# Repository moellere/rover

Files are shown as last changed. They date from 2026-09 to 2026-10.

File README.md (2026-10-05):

# Grover

A small rover built from Makeblock parts, living on a garage workbench and
learning to look after itself. Named Grover on 2026-09-29: blue rails, and it
spends its life demonstrating *near... far*.

This repo is the whole project: a dated [journal](JOURNAL.md) of what
happened and who decided it, the [bill of materials](BOM.md) against a $100
budget, the [roadmap](ROADMAP.md), the off-board brain, printable hardware,
scripts, and a reference copy of the firmware.

It is a collaborative build between Enoch and Claude (Anthropic). The
journal records which model did the work at each stage and which decisions
were Claude-driven versus Enoch-directed. [CLAUDE.md](CLAUDE.md) is the
standing rulebook (mission, hard constraints, budget policy, permissions,
safety rules learned the hard way) - auto-loaded by Claude Code as project
instructions, and readable as plain English by anyone.

## The mission

1. **Phase 1 (current):** drive around the workbench without falling off.
2. **Phase 2:** recharge itself.
3. **Phase 3:** roam the house.

## Where it stands (2026-10-05)

- **Visual homing works.** `home_to_marker` finds a printed ArUco marker
  with the onboard camera and parks in front of it, unattended.
- **It has been through the house.** On 2026-10-04 Grover drove from the
  dining room through the foyer and living room to the kitchen doorway
  (~12-14 m) in short, camera-checked legs, stopping itself for a dog,
  people and sun glare. Hardwood and rugs both fine.
- **Spinal cord is an ESP32** (`rover32`, since 2026-10-03) with no I/O
  expander; the TFMini LiDAR sits alone on its own I2C bus.
- **Sensors:** TFMini forward LiDAR (obstacle stop at 50 cm), two TCRT5000
  cliff sensors on mounts that put each one ahead of its wheel, the rover
  camera, and two bench cameras (one behind, one head-on PTZ).
- **Chassis is the trike build** (two driven wheels, trailing caster). The
  swivel caster twists the rear on stops; a fixed printed skid
  (`hardware/caster-skid.scad`) replaces it next.
- **The house chassis works too:** a Eufy RoboVac 12 driven over IR from
  `blackcam`, a T-Camera on its lid (camera + IR LED driver). It has backed
  off its dock and returned on command.
- Known hazard: no rear cliff sensors, and reversing a trike is
  unpredictable - see the reversing rule in `CLAUDE.md`.

## Architecture

Three layers, decided early and still standing:

| Layer | Hardware | Role |
|---|---|---|
| **Spinal cord** | ESP32 devkit (`rover32`, since 2026-10-03; was a Wemos D1 Mini), ESPHome | reflexes: watchdog, disconnect-stop, cliff, battery and TFMini obstacle guards, kick start, optional brake-on-stop. Authoritative - nothing off-board can override them. |
| **Eyes** | TTGO T-Camera (ESP32-WROVER, OV2640), ESPHome | snapshot and stream endpoints; no decisions |
| **Brain** | `brain/` - Python + OpenCV, off-board | everything with judgment: marker detection, the homing loop, bounded drive pulses. Exposed as an MCP server (`rover-brain`). |

Claude (the model) is *not* in the control loop: it starts a run and reads
the log. A homing run is a plain Python loop - look, decide one pulse,
settle, look again - talking to the rover over ESPHome's native API.

## Hardware

- Chassis: Makeblock Starter Robot Kit, **trike** configuration; two DC gear
  motors, trailing swivel caster (to be replaced by a printed fixed skid)
- Controller: ESP32 devkit (`rover32`) - motor enables on GPIO16/17,
  direction on GPIO18/19/22/23, cliff inputs GPIO35/32, TFMini I2C on
  GPIO25/26, battery sense on GPIO34. (Was a Wemos D1 Mini + MCP23008.)
- Motor driver: L298N dual H-bridge
- Power: 3x 18650 Li-ion in 3S (12.6 V full); LM2596 buck at 5.2 V for the
  ESP32, the camera and the TFMini; battery voltage through a 100k/27k
  divider (calibrated to the meter). A 3S BMS board is in hand, not fitted.
- Sensing: Benewake TFMini LiDAR on a printed bracket (direct GH1.25 lead,
  5 V); two TCRT5000 cliff modules at 3.3 V on printed v4 mounts
- Vision: TTGO T-Camera on the rover (fisheye, ~111 deg); two Thingino
  cameras on the bench (`camv3` behind the rover, `fishcam` PTZ head-on)
- Homing targets: ArUco 4x4_50 markers, ids 0 (80 mm) and 1 (160 mm),
  printable from `hardware/markers/`

## Software

- **Firmware:** ESPHome (`firmware/rover32.yaml` for Grover,
  `firmware/blackcam.yaml` for the Eufy's lid board; `rover.yaml` and
  `eufy-ir.yaml` are retired - all reference copies; the live configs with
  secrets are in a private repo).
  Custom services `forward`/`backward`/`left`/`right`/`stop`; `Drive duty`
  `Pivot duty` and `Left trim` (+6 %, calibrated) sliders; a `Brake on stop` switch (boots off); `Obstacle stop` distance (50 cm).
- **Brain:** `brain/` - MCP tools `status`, `snapshot(bench|front|rover)`, `set_brake`, `set_obstacle_stop`,
  `drive` (capped at 1 s, refused on low battery or cliff), `find_marker`,
  `home_to_marker`, `stop`. Install with `scripts/install-brain.sh`; details
  in `brain/README.md`.
- **Printing:** parametric OpenSCAD in `hardware/` (camera cradle, adapter
  strip, TFMini bracket, cliff-sensor mounts, caster skid, marker pages, a
  shelved Roomba plug), sliced with the house rules
  (PETG, no brim, tree supports on auto) and printed through the
  print-warden service; toolchain via `scripts/install-tools.sh`.
- **Scripts:** `rover_ctl.py` (drive over the native API),
  `test_disconnect_safety.py` (proves the disconnect-stop),
  `camera_snapshot.py`, `warden_call.py` (talk to the print-warden from a
  shell). All read hosts and credentials from environment variables.

### Safety design

A device that can drive off a table needs more than "send stop when you
mean it." In the firmware, always on:

- **Command watchdog** - no drive command for 1.5 s -> motors stop.
- **Disconnect-stop** - the API client goes away for any reason -> motors
  stop. Verified by `scripts/test_disconnect_safety.py`.
- **Cliff guard** - a front IR sensor stops seeing the bench -> forward and
  pivots refused (backward stays allowed).
- **Battery guard** - below 9.3 V the rover refuses to drive; resumes above
  9.6 V. Rolling 25 s average, ignored for 20 s after boot (a latched-low
  bug from a bad first sample was fixed 2026-10-05).
- **Obstacle guard** - the TFMini (polled every 50 ms) refuses and cuts
  forward motion inside 50 cm; "was under 60 cm, now too close to measure"
  counts as an obstacle (a wall met at an angle slipped through before).
- **Kick start** - 100 ms at full power from rest so both wheels break
  stiction together, then the set duty and trim.
- **Brake-on-stop** (switch, boots off) - shorts the windings for 150 ms on
  every stop. Measured: no change in distance and it didn't stop the
  end-of-pulse yaw (the swivel caster did that).

The brain adds courtesy limits on top (pulse cap, gap between pulses,
lost-marker and stuck detection) but never replaces the firmware's.

## The house chassis: a Eufy RoboVac 12

Phases 2 and 3 ride on a **Eufy RoboVac 12**, keeping its own docking,
charging, cliff and bumper behaviour, driven over infrared. Its remote
sends a 6-byte frame `68 CMD HH MM 5C SUM` - **the current time is stamped
into every command**, and stale frames are ignored. `blackcam`, a T-Camera
on the lid (`firmware/blackcam.yaml`), stamps each frame from SNTP and
drives a 940 nm LED through an NPN transistor (~105 mA, 2 m range). It has
backed the Eufy off its dock and sent it home. See Tier 2E in the roadmap.

## First drive

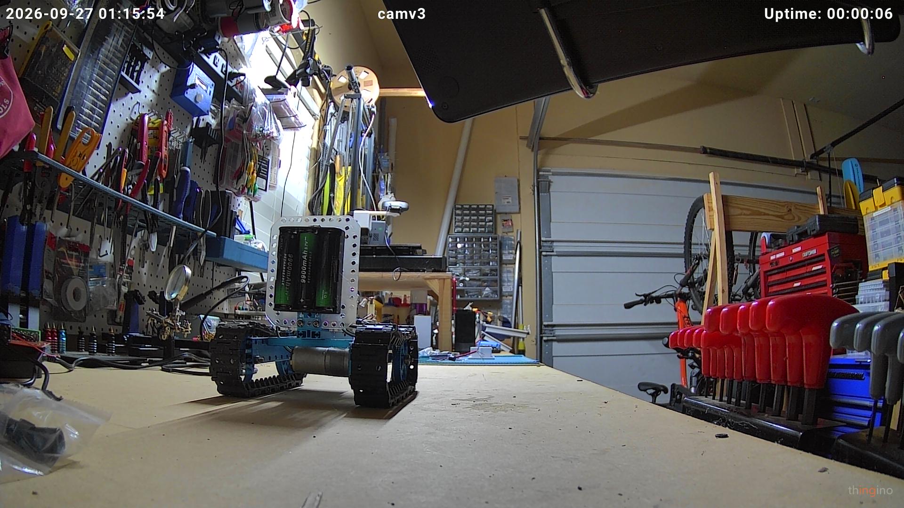
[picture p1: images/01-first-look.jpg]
First look at the workbench, lights on

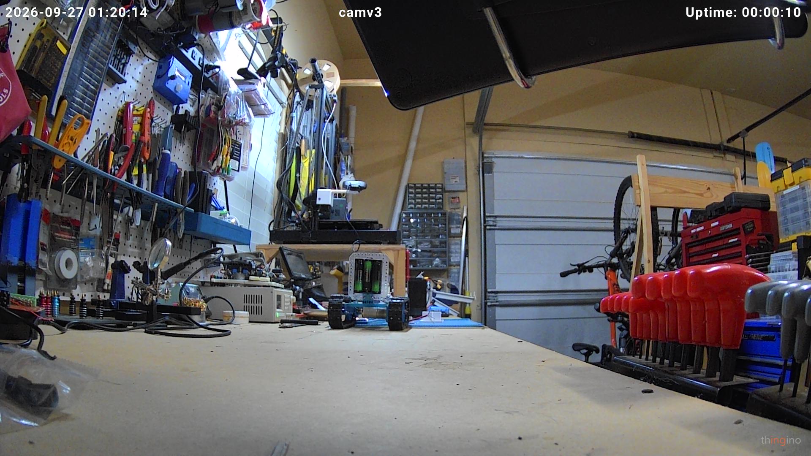
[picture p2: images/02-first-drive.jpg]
Mid-drive, having moved a full bench-length

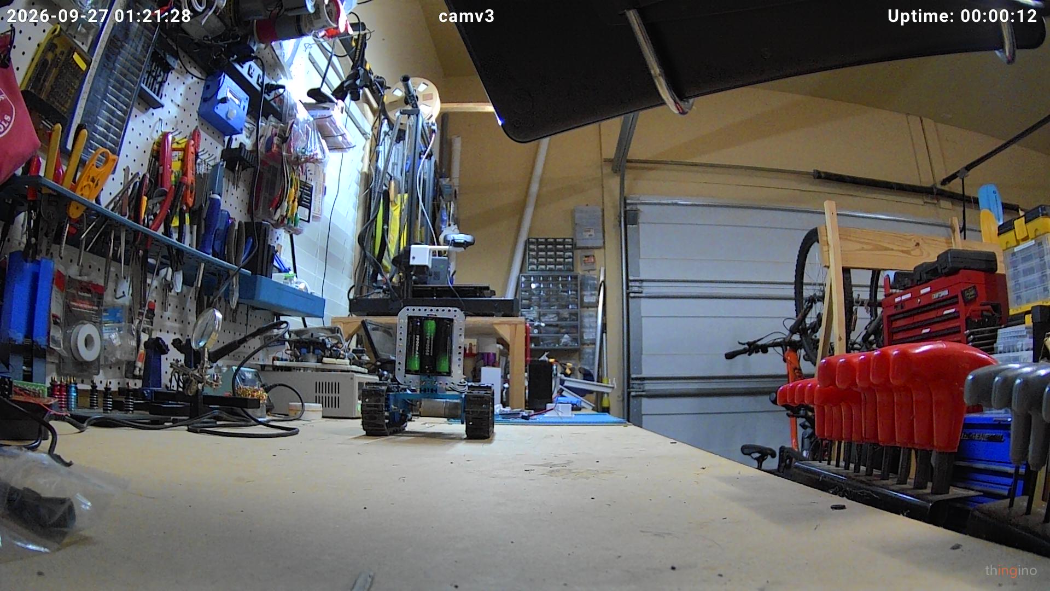
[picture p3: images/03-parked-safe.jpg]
Parked safely after the session


## Budget

Parts already in Enoch's inventory are supplied by him. Anything else comes
out of a standing **$100 budget** tracked in [BOM.md](BOM.md). Spent so far:
$0.00.

---

Built and driven in collaboration with Claude (Anthropic).

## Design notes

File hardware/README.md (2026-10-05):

# Hardware designs

Parametric OpenSCAD parts for the rover. Install the toolchain with
`scripts/install-tools.sh` (OpenSCAD 2021.01 + OrcaSlicer 2.4.2, no root
except for the one `apt-get` line noted at the top of that script).

## Parts

| File | What | Status |
|---|---|---|
| `roomba-minidin-plug.scad` | 7-pin mini-DIN plug body for the Roomba's Open Interface port: seven solid-core wires held at the pin positions, keyed insert, gripped body. | **Shelved** - the Roomba was gone (issue #1). Test print #1 taught two fixes, now in the file: inset key groove instead of a rib, larger wire holes. Ready if a mini-DIN port reappears. |
| `camera-mount.scad` | Cradle that stands the TTGO T-Camera upright on the Makeblock plate, lens/PIR/OLED facing forward, tilted 10° down. Open front, back window for the micro-USB lead, M4 slots on the plate's 8mm grid. | Board dimensions measured by Enoch (28.0 x 68.0 x 1.27 mm, 6 mm rear components). **v5 printed and in use** (`prints/camera-mount_v5`): corner lips, straight-down cable slot, inside tabs. Known quirk: the base's cable slot breaks into its two M4 slots - use washers under the screw heads. |
| `camera-strip.scad` | Adapter strip that bolts the v5 cradle rigidly to the chassis: spans the two front M4 standoffs (64 mm c-c, 30 mm tall, slotted for 63-66), presents the cradle's own 8 mm-grid M4 slots on top, 8 mm cable slot underneath. Runs left-right; camera centred. | Designed from Enoch's measurements 2026-09-29 (68.5 mm across the outer edges of the standoff holes). Sliced as `prints/camera-strip_v1` (21 min, 8.8 g PETG, no supports). **Printed 2026-09-29** (Enoch's go-ahead in chat). Fit-check after the trike rebuild. |
| `tfmini-bracket.scad` | TFMini bracket: sits on the front cross beam's top face, bolts through the holes at x = +/-12 mm (M4 x 20 + nut, slotted +/-2 mm front-back), with a relief pocket over the centre pair (taken by the under-beam bracket to the caster beam); a plate in front of the beam carries the sensor by its ears (M2, 36 mm c-c, Benewake drawing), centred at beam mid-height, lenses forward. Prints on the sensor face. | Beam assumed Makeblock 0824 (24 deep, 8 tall, holes mid-face on the 8 mm grid) - Enoch confirmed top/bottom holes, standard spacing, not threaded. Print-warden job `010780c633` (29 min, 7.9 g PETG), **Printed 2026-09-29** (Enoch: "OK, print it"; done in 36 min). Fit-check pending. |
| `cliff-mount.scad` | Cliff sensor mount, one per side (`side="right"|"left"` mirrors): foot on the front beam's top face at the end holes (front row, M4 x2 + nuts), plate dropping in front of the beam face past the motors, shelf at the bottom with the HW-870 module hanging under it on a 6 mm spacer boss (M3 + nut), sensor face ~8 mm above the bench, ribs stop it rotating. Prints on its side. | Beam top 51 mm above the bench, module 31.5 x 14, hole centre 7.5 mm from the pin end (Enoch, 2026-10-03). v1 right printed 2026-10-03 (Enoch: ribs stopped short of the screw, board could pivot). v2 (ribs longer along the shelf) printed left - but the ribs were only boss-high, so they never reached the board's edges. **v3** ribs come down past the board (boss + PCB + 2 mm) either side of it: staged right `3ec7dae6cc`, left `2f3cdb2627` (30 min, 9.3 g PETG each). |
| `caster-skid.scad` | Fixed domed PETG skid replacing the swivel caster (which twisted the rear on stops). 22 mm puck, 36 mm tall (bracket underside to bench), M5 bolt down through the block into a captive nut slid in from the side. Round, so the single bolt can't steer it. | Enoch's measurements 2026-10-05. Staged on print-warden `d211dc8852` (28 min, 6.2 g PETG), not started. Needs an M5 bolt ~25-30 mm and a nut. |

## Render

```
openscad -o camera-mount.stl camera-mount.scad
```

The `.stl` is committed alongside the `.scad` so it can be inspected without
the toolchain, but the `.scad` is the source of truth - regenerate the STL
after any edit.

## Slice and print

Printer: Artillery Sidewinder X4 Plus (Klipper/Moonraker), 300 x 300 bed,
0.4 mm nozzle, PETG loaded. OrcaSlicer ships a matching profile
("Artillery Sidewinder X4 Plus 0.4 nozzle") and a Generic PETG filament.

House rules for every slice: **tree supports** if supports are needed at
all, **no brim**. Claude slices; Enoch starts the print.

Headless slicing (no display) goes through `orca-slice-headless`, a wrapper
that runs Orca's CLI under `xvfb-run` - installed by `install-tools.sh`.

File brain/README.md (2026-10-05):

# Rover brain (MCP server)

The high-level front door to the rover: an MCP server that Claude (or any
MCP client) talks to instead of poking ESPHome services and camera URLs by
hand. It runs off-board - on the dev VM today, on the cluster later - and
is where autonomy (visual homing, docking) will be written.

Architecture, for the record: an ESP32 (`rover32`) is the *spinal cord*
(ESPHome; watchdog, disconnect-stop, cliff, battery and obstacle guards in
firmware), the
T-Camera stays the *eyes* (ESPHome; snapshot/stream), and this service is
the *brain*. The firmware guards are authoritative; this server only adds a
courtesy layer that refuses obviously bad requests early.

## Tools

| Tool | What it does | Limits |
|---|---|---|
| `status` | motion, battery voltage, both cliff sensors, uptime, WiFi dBm, `brake_on_stop`, TFMini `front_range_cm`/`front_range_valid`, `obstacle_stop_cm` | - |
| `snapshot(camera)` | JPEG from `bench` (camv3, behind the rover), `front` (fishcam, across the bench, head-on) or `rover` (onboard T-Camera) | - |
| `drive(direction, seconds)` | pulse `forward`/`backward`/`left`/`right`, then stop | capped at 1.0 s per call, 0.3 s gap between pulses, refused below 9.6 V or when a cliff sensor is active (backward still allowed) |
| `find_marker(camera)` | ArUco 4x4_50 markers in a fresh frame: id, pixel centre, apparent size, bearing (+ = right), distance in mm (per-camera calibration via `BENCH_CAM_FOCAL_PX` / `ROVER_CAM_FOCAL_PX`; bench cam calibrated 2026-09-29 at 1062 px, rover cam at 437 px, front cam not yet (`FRONT_CAM_FOCAL_PX`). A CLAHE contrast pass retries frames where plain detection finds nothing (backlit marker) - a ~111 deg fisheye, so the 80 mm marker decodes only within ~1 m; use the 160 mm id-1 marker beyond that) | - |
| `set_obstacle_stop(cm)` | firmware TFMini guard distance; 0 = off. Boots at 50; `home_to_marker` relaxes it once the camera has the marker inside that distance, and restores it after | - |
| `set_brake(on)` | firmware `Brake on stop` switch (boots off) | - |
| `locate(camera)` | overhead marker poses: Grover's position and heading from ArUco id 2 (60 mm, taped on top, FRONT edge to the nose; page in `hardware/markers/`), plus any other markers; image-frame angles, local mm/px | - |
| `eufy(command)` | drive the Eufy RoboVac 12 over IR via its lid board: forward, backward, left, right, home, start_stop (one remote press each; floor only) | - |
| `stop` | stop now | - |

Orientation note: on the bench, `forward` moves the rover away from the fixed
bench camera (the camera sees its rear); `backward` moves it toward the
camera and the near edge.

`home_to_marker(marker_id, stop_mm, max_pulses)` - the closed loop in
`homing.py`: look with the rover camera, pivot toward the marker if it's off
centre, else step forward, settle, look again. Per-direction adaptive pivot
pulses, a stuck guard, retries on transient camera errors, and arrival by
lateral offset (the big marker overfills the frame inside ~200 mm, which
counts as arrived). Printable markers: `hardware/markers/` (id 0 = 80 mm,
id 1 = 160 mm; use id 1 beyond ~1 m). Reversing is deliberately not part of
the loop - see the reversing rule in the project `CLAUDE.md`.

## Hosting

**Hosted since 2026-10-05** on the home Kubernetes cluster: Argo CD app
`app-rover-brain` (moellere/argocd, `applications/rover-brain/`), namespace
`rover-brain`, image `ghcr.io/moellere/rover:X.Y.Z` (built by
`.github/workflows/brain-image.yml` on `v*` tags - bump the tag in the
argocd manifest to deploy), endpoint `https://rover-brain.dorktool.com/mcp`
behind Traefik basic auth; credentials as SealedSecrets. Placement chosen by
the homelab-helper session. The user-scope `claude mcp` entry `rover-brain`
points there; `rover-brain-local` is the stdio copy on the dev VM.

`brain/Dockerfile` builds a container that serves **Streamable HTTP on
:8000 at `/mcp`** (`BRAIN_TRANSPORT=http`). Locally it still runs over
stdio via `brain/run.sh`. Every host, key and password comes from the
environment (`brain/env.example` lists them) - in the cluster, a Secret.

## Install and run

```
scripts/install-brain.sh            # venv at brain/.venv with the MCP SDK, aioesphomeapi, OpenCV
cp brain/env.example ~/.rover-brain.env && $EDITOR ~/.rover-brain.env
brain/run.sh                        # stdio server (what an MCP client launches)
```

Register with Claude Code so it appears as a tool set in every session:

```
claude mcp add rover-brain --scope user -- /path/to/rover/brain/run.sh
```

No host, key, or password is stored in this repo or in the MCP registration
- `run.sh` reads them from `~/.rover-brain.env` at launch.

## Files

- `server.py` - the MCP server (FastMCP) and its safety limits
- `rover_client.py` - ESPHome native-API wrapper (state, drive, stop)
- `cameras.py` - still-frame capture from both cameras
- `run.sh` - launcher; `env.example` - the variables it expects

## Bench camera day/night

The Thingino bench camera can be forced between modes for night-time marker
work: `GET /x/json-imp.cgi?cmd=daynight&val=night` (or `day`, `read`);
its IR floodlights toggle with `cmd=ir850|ir940&val=0|1`. Restore `day`
afterwards.

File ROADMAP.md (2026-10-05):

# Roadmap

Claude's proposed sequence of capabilities, written 2026-09-28 (Fable 5.1),
last updated 2026-10-05 (Opus 5.5)
at Enoch's request. Ordered by dependency, not by fun - though there's fun
in every tier. Budget notes assume the $100 pool in `BOM.md`; "inventory"
means Enoch already has it. Enoch reshapes this freely; it's a proposal.

## Tier 0 - finish the bench (Phase 1 close-out)

| # | Item | Needs | Why |
|---|---|---|---|
| 0.1 | ~~Print and fit the camera mount~~ **done** (v5) | - | everything visual depends on it |
| 0.1a | ~~Rebuild the chassis as the trike~~ **done 2026-09-29** (drive wheels front, caster rear) | - | the tank skidded its tracks to pivot - stiction, asymmetry, 100% duty bursts; wheels pivot cleanly at low duty. Decided 2026-09-29. Then re-tune `PIVOT_S`/`FORWARD_S` in `brain/homing.py` |
| 0.1b | ~~Camera adapter strip fitted~~ **done 2026-09-29** | - | bolts the cradle to the front standoffs so bearings stop drifting with every pulse |
| 0.2 | ~~Camera on rover power~~ **done** (buck -> spliced USB) | - | camera travels with the rover |
| 0.3 | ~~Camera firmware for the rover role~~ **done** (5 fps idle, PSRAM) | - | snapshots are fresh; stream still SXGA - drop to VGA if latency matters |
| 0.4 | ~~Cliff sensors installed~~ **done 2026-10-04** (3.3 V, GPIO35/32; mounts v4 put each sensor on its tyre centreline 65 mm ahead of the axle) | - | read clear on bench, hardwood and rugs; trip when lifted. Edge-stop drive test still to do |
| 0.5 | ~~Brain driving verified~~ **done** | - | ~22 cm per 0.3 s pulse on hardwood (more with the kick start); +6 % left trim |
| 0.7 | Caster skid | print `hardware/caster-skid.scad` (staged), M5 bolt + nut | the swivel caster yaws Grover 20-30 deg on stops; locked straight, it stops square (2026-10-05) |
| 0.8 | Cliff edge-stop test | 0.4, 0.7 | drive slowly at the bench edge; the firmware must stop before a wheel crosses |
| 0.6 | Home Assistant cleanup | - | re-add the rover so battery/motion/cliff show on the dashboard; add both camera feeds to the workbench section |

## Tier 1 - visual homing (the proposed next goal)

Success test: from anywhere on the bench, the rover finds the marker and
parks nose-on within ~2 cm, unattended.

| # | Item | Needs | Notes |
|---|---|---|---|
| 1.1 | Printed marker | paper, `hardware/markers/` (done) | ArUco 4x4, id 0, 80 mm - printable page committed |
| 1.2 | `find_marker` tool | camera mounted | detector already in `brain/markers.py`; returns id, pixel centre, apparent size, bearing |
| 1.3 | Camera calibration | a ruler and the marker | focal length from marker size at known distances -> distance estimate |
| 1.4 | `home_to_marker` | 1.2, 1.3, 0.5 | **done 2026-09-29** - closed loop with adaptive pivots; arrivals: 12 pulses 594 -> 90 mm (80 mm marker), 14 pulses 667 -> 214 mm (160 mm marker) |
| 1.4a | ~~Re-tune homing on the trike~~ **done 2026-09-29** | - | pivot duty 50% (live slider), `PIVOT_S` 0.1 s ~6 deg, near step 0.1 s; first trike arrival 1109 -> 168 mm in 7 pulses |
| 1.5 | Bench lap demo | all above | drive a lap around a clutter-free zone using markers as waypoints |

## Tier 2E - the Eufy path (issue #1; revised 2026-09-28)

The Roomba turned out to be gone; Enoch has a **Eufy RoboVac 12** instead.
Decision: it becomes the house chassis, driven over **infrared** - the
11/11S/12 family is controlled by an IR remote, and ESPHome already drives
them with an IR LED and published Pronto codes. That keeps the vacuum's own
docking, charging, cliff and bumper behaviour intact (recharging solved, as
with the Roomba) at the cost of telemetry: no encoders or sensor readouts
come back over IR. The camera and brain ride on the lid; the brain steers by
vision. A later, deeper step taps the battery voltage and charging signal
inside the shell (also a known hack). Bench work (Tiers 0-1) is unchanged
and comes first.

| # | Item | Needs | Notes |
|---|---|---|---|
| 2E.1 | Health check | Enoch: does it run and dock-charge; is the remote around | a dead pack changes the plan (~$20-30 from budget) |
| 2E.2 | ~~Codes~~ **done, and decoded** | the remote's own frames | frame `68 CMD HH MM 5C SUM` - the time is stamped into every command; CMD: fwd 2C, back 7C, left 3C, right 6C, home EF, start/stop 4F |
| 2E.3 | ~~IR transmitter~~ **done 2026-10-04** - on `blackcam` (2E.5) | ESP32 hardware (RMT) carrier, SNTP-stamped frames, NPN driver (~105 mA) | forward, backward and home confirmed; 2 m range. The ESP8266 software carrier never decoded; a C3 Super Mini config is kept as a spare |
| 2E.4 | Brain backend | 2E.3 | same `drive`/`stop` tools; `status` limited to what the camera sees until 2E.6 |
| 2E.5 | ~~Camera on the lid~~ **board done 2026-10-04: `blackcam`** | a second T-Camera (powers from its header 5 V) doing camera **and** IR (LED driver on IO22; OLED dropped so the I2C bus stays quiet) | next: mount it on the lid and power it from the Eufy (buck from its battery, 2E.6) or a USB bank |
| 2E.6 | Inside-the-shell telemetry (later) | open it up: battery voltage via divider, charging signal | published 11S wiring exists; gives low-battery and docked state |

## Tier 2 - recharging (Phase 2) - *now the Makeblock-only path; deferred unless the Eufy falls through*

| # | Item | Needs | Notes |
|---|---|---|---|
| 2.1 | Dock design | 3D print | a wedge the rover drives into, marker on its face, contacts at the end of travel |
| 2.2 | Charge contacts | pogo pins or copper strips (~$5-10 budget) | on the rover's nose and the dock |
| 2.3 | 3S charger + protection | protection half **ordered 2026-09-29** (3S 40A BMS, see BOM); still needs a 12.6 V CC/CV charger for in-place charging | charging the pack in place, safely - the one piece of this project with real fire risk; design reviewed with Enoch before anything is wired |
| 2.4 | Auto-dock | 1.4, 2.1-2.3 | return-to-dock when `battery_voltage` drops below a threshold; confirm charging via voltage rise |
| 2.5 | Charge telemetry | 2.3 | charging state and current into the brain and HA |

## Tier 3 - robustness and efficiency

| # | Item | Needs | Notes |
|---|---|---|---|
| 3.1 | ~~Spinal cord on the buck~~ **done** (ESP32 fed from the buck at 5.2 V) | - | the L298N's linear regulator no longer feeds the controller |
| 3.2 | Camera sleep | firmware | deep-sleep or stream-off when nobody is watching; wake on demand |
| 3.2a | **Low-battery deep sleep** | firmware (rover + redcam) | below ~9.6 V with no command for 5 min, both ESPs deep-sleep and wake every 30 min to report voltage. The 9.3 V guard only stops *driving*; idle draw (~2.5 W: two ESPs + L298N regulator + buck) flattens a full pack in ~12 h, into cell-damage territory. Until this exists, Enoch switches the pack off when done (2026-09-29). |
| 3.2b | **Hardware low-voltage cutoff** - 3S BMS board **in hand** (2026-10-03; wiring: balance pads are taps, pack negative re-routes through B-/P-), install deferred | - | the real fix - the ESPs can't cut the regulators' quiescent draw. Goes inline with the pack switch. |
| 3.3 | Wheel odometry | 2 encoders or IR sensor + slotted disk (~$5-10 budget) | distance/heading without timing guesses; needed for anything beyond line-of-sight to a marker |
| 3.4 | Forward range / obstacle sensing | **Benewake TFMini + SparkFun Qwiic adapter (inventory)** | **Live 2026-10-03:** mounted in the printed bracket, 78 cm vs 77 cm by tape. Guard now **50 cm, polled every 50 ms** (a kicked pulse ended 15 cm from a box at 35 cm), plus "close then invalid" = obstacle; homing relaxes it inside its distance. On the ESP32 it has its own I2C bus (repeated-start reads, 100 kHz, 20 ms stretch limit). Original plan, for history: Plan: on the D1 Mini's I2C bus (3.3 V logic, D1/D2, next to the MCP23008) at address 0x10 - write `01 02 07`, read 7 bytes (valid flag, -, dist LSB/MSB in cm, strength LSB/MSB, range type). Power the TFMini's 5 V pin from the buck (peaks ~800 mA; the adapter's 3.3 V boost can't run it from the D1 Mini). Firmware guard: refuse forward when range < ~35 cm and an obstacle is ahead. **Minimum range is 30 cm**, so the camera keeps the last 20 cm of a homing approach; the LiDAR owns the lane. ESPHome has no built-in component - read it with an I2C lambda in a template sensor, or a small external component. |
| 3.4a | Brake on stop - switchable, **boots off**: no measurable change in distance (09-29) and no cure for the end-of-pulse yaw (10-05 - the caster, see 0.7) | rover firmware (Enoch OK'd) | `stop` shorts the windings for ~150 ms (both IN pins on, EN high) before releasing - cuts the coast from ~8 cm to ~3 cm at cruise; matters most for the cliff stop |
| 3.4d | Spinal cord on an ESP32 - **done 2026-10-03: `rover32` live, no expander, TFMini on its own bus, battery calibrated, drive verified on the bench** | ESP32 devkit (inventory); port of `rover.yaml`, first flash by USB | TFMini on its own I2C bus so a stuck sensor can't take the MCP23008 (motors, cliff) down; spare UARTs; prerequisite for one-board consolidation (3.5) |
| 3.4b | Rear cliff sensors | 2 more IR modules, GPIO33/13 reserved | reversing is blind today; near miss 2026-09-29 |
| 3.4c | ~~Brain as a hosted service~~ **done 2026-10-05** (k8s app `rover-brain`, ghcr image, basic-auth ingress; placement by homelab-helper) | container + MCP endpoint; placement via homelab-helper | for unattended runs and persistent state (Phase 3); the dev-VM script is a bench-phase arrangement |
| 3.5 | One-board consolidation | - | partly moot: the ESP32 spinal cord has pins to spare; folding the camera in is the remaining step, and blackcam already shows a T-Camera can carry an extra job |
| 3.6 | Brownout watch | - | log resets/WiFi drops; add the rail capacitor if they show |

## Tier 4 - roaming the house (Phase 3)

| # | Item | Needs | Notes |
|---|---|---|---|
| 4.1 | Floor-safe cliff sensing | stairs | hardwood and rugs read correctly (2026-10-04); stairs untested. Direct sunlight may affect the TCRT5000s |
| 4.2 | Obstacle avoidance | 3.4 | the house run showed the TFMini's narrow beam misses off-centre things (a sideboard leg, a low box); the camera per pulse is required. Eufy bumpers do this better |
| 4.3 | Room awareness | markers per doorway or HA presence | "which room am I in" before any mapping |
| 4.4 | Waypoint navigation | 3.3, 4.3 | marker-to-marker routes between rooms |
| 4.5 | House rules | Enoch | where it may go, quiet hours, what to do when it meets an animal (stop, retreat) |

## Tier 5 - operations and fun

| # | Item | Notes |
|---|---|---|
| 5.1 | Brain as a hosted service | container on the cluster next to the other MCP servers; streamable HTTP |
| 5.2 | Rover dashboard view in HA | cameras, battery graph, motion/cliff state, last snapshot |
| 5.3 | Telemetry log | battery over time, drive history - feeds the journal's numbers |
| 5.4 | Patrol mode | scheduled lap with snapshots posted to HA |
| 5.5 | Voice | announcements through the Echo Pyramid ("docking", "low battery") |
| 5.6 | OLED face | the T-Camera's screen shows state/expressions instead of an IP address |

## Parts likely on hand (from the ESPHome configs and wirestudio's library)

Enoch pointed at wirestudio and the ESPHome repo as a view of what he has.
The catalog is a superset of the inventory, so each of these is a "check
the bin" rather than a certainty - but every one maps to a roadmap item and
would cost $0 if present:

| Part (catalog / in use) | Roadmap use |
|---|---|
| HC-SR04 ultrasonic (in use on one device), VL53L0X ToF | 3.4 obstacle sensing; 4.2 house obstacles |
| MPU6050 / BMI270 IMU (BMI270 in use) | heading hold for pivots; dead-reckoning between markers |
| INA219 current/voltage sensor | real battery state (current + voltage) on either rover; charge detection on the Eufy |
| PCA9685 16-ch PWM | 3.5 one-board consolidation (T-Camera drives the L298N over I2C) |
| Rotary encoder / pulse counter (both in use) | 3.3 wheel odometry on the Makeblock |
| LD2410 / LD2420 radar (10 devices use LD2420) | person/pet detection ahead - 4.5 house rules ("stop for animals") |
| WS2812B / NeoPixel (25 devices) | status ring on the rover; "eyes" |
| I2S mic + MAX98357A speaker (in use on the audio devices) | 5.5 voice on the robot itself, not just the Echo |
| HC-SR501 / RCWL-0516 motion | cheap "someone's here" wake-up for patrol mode |
| esp32-wrover-cam board profile | second camera (rear / downward for cliff verification) |

Bin check (2026-09-28): **HC-SR04, an IMU, and a PCA9685 are on hand**; no
wheel encoders that fit the Makeblock motors, so 3.3 odometry leans on the
IMU + timing (or a later optical encoder on a motor shaft). INA219 and
VL53L0X unconfirmed.

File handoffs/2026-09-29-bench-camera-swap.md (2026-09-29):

> Note (rover session): this repo is public; LAN addresses were removed from this note on
> arrival. Hosts live in `~/.rover-brain.env` and the user-scope `claude mcp` entries.

# Handoff: bench camera swap (from the homelab-helper / print-warden session, 09/29/2026)

**Proposal, agreed with Enoch on 09/28/2026:** the rover's bench camera changes from **camv3** to
**fishcam**. camv3 moves to the Sidewinder X4 as the fixed whole-bed camera for print-failure detection.
Nothing has been moved yet; Enoch will do the physical swap when he gets to it. This note is so the rover
side is ready and nothing silently breaks.

## What changes for the rover

| | Today | After the swap |
|---|---|---|
| Bench camera | camv3, Wyze Cam v3 on Thingino, (camv3's LAN address - see ~/.rover-brain.env), fixed | fishcam, Wyze Cam **Pan** v2 on Thingino, (fishcam's LAN address - kept out of this public repo), **PTZ** |
| `BENCH_CAM_HOST` in `brain/` | (camv3's LAN address - see ~/.rover-brain.env) | (fishcam's LAN address - kept out of this public repo) |
| Snapshot path | `/x/image.cgi` (basic auth) | same firmware, same path expected; confirm the password (Thingino creds are per camera) |
| PTZ | none | yes, already exposed in Home Assistant via the ONVIF integration (`camera.wyzecampanv2_1_profile_1`, `onvif.ptz` service). Two presets suggested: "bench" for the marker/rover view, "wide" for the whole table |
| Frigate | both cameras stay in Frigate on covomv under their current names; snapshots also available at `the Frigate server's `/api/<name>/latest.jpg`` | unchanged |

Things to watch after the move:
- `find_marker` was calibrated against camv3's mount and lens. fishcam has a different sensor, lens and
  height, so expect a one-time re-check of marker size/bearing and the "bench" preset aim.
- camv3 has been flapping on 2.4 GHz through the playroom AP (182 ffmpeg restarts in 48 h on 09/28). fishcam
  is coming from the dining room; after the move, check it associates with the **garage** AP (the X4 does)
  and pin it in UniFi if it clings to another one.
- The overlay text (timestamp/name) on the Thingino stream is fine for the rover; it will be turned off on
  camv3 only, for the print detector.

## Context you may want

- Print side: the C920 on the X4's X beam stays as the nozzle/layer camera; camv3 becomes the elevated
  fixed view (200 mm above the bed, 35° down, on a post from the left base rail or off-machine).
  Drawing: https://claude.ai/artifact/7QAXDaFi9hM1tywUgeNPcZ
- Printing from the rover project now goes through the **print-warden** MCP (`print-warden` in user-scope
  `claude mcp`, the print-warden server's `/mcp` endpoint): `curl -F file=@part.stl the print-warden server's `/upload` endpoint`, then
  `submit_job(printer="covington", model="part.stl", material="PETG")` slices with your house rules (tree
  supports, no brim, Artillery X4 Plus presets) and stages the gcode; Enoch starts it from a phone tap or
  by giving permission in chat (`start_print(job_id, authorized_by=...)`). `hardware/slicing/slice.sh` still
  works locally; the warden reuses `scripts/orca_flatten_preset.py` and `house-rules.json` verbatim.
- Generic PETG white is loaded on the X4 (Spoolman spool 2); the X1 at Wyola has PETG black (spool 4).

Questions or objections: reply to the homelab-helper session (`homelab-helper-b2`) or leave a note here.

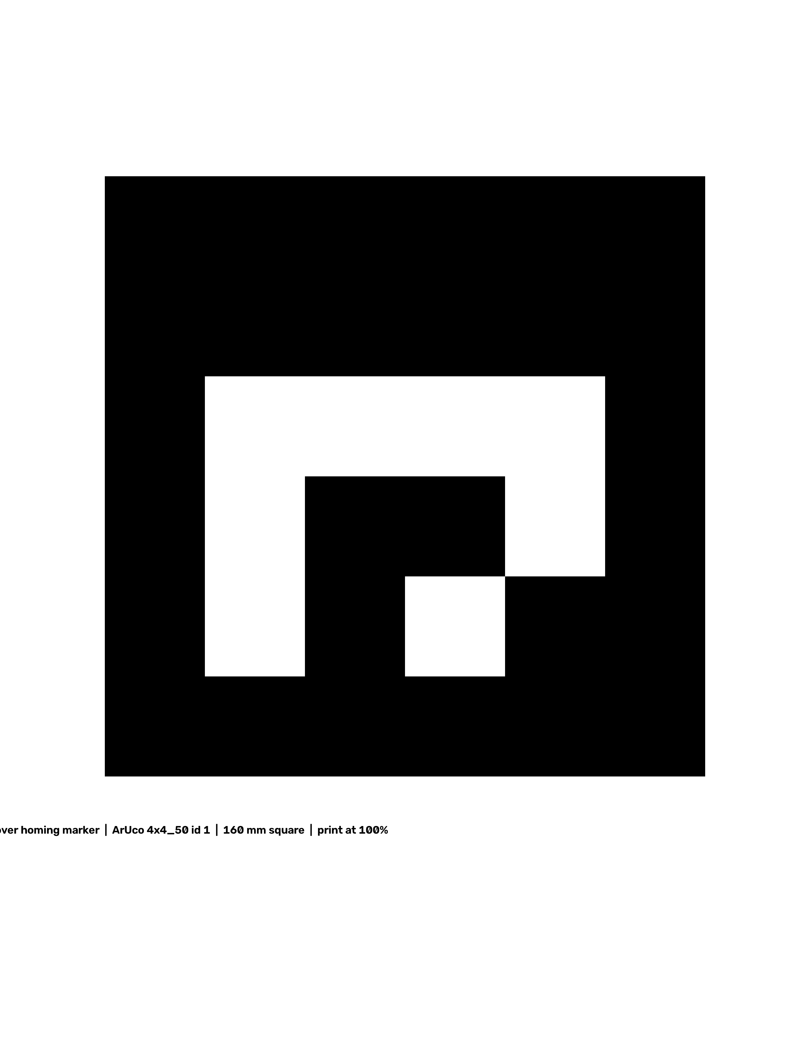
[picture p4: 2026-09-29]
hardware/markers/aruco_4x4_50_id1_160mm.png

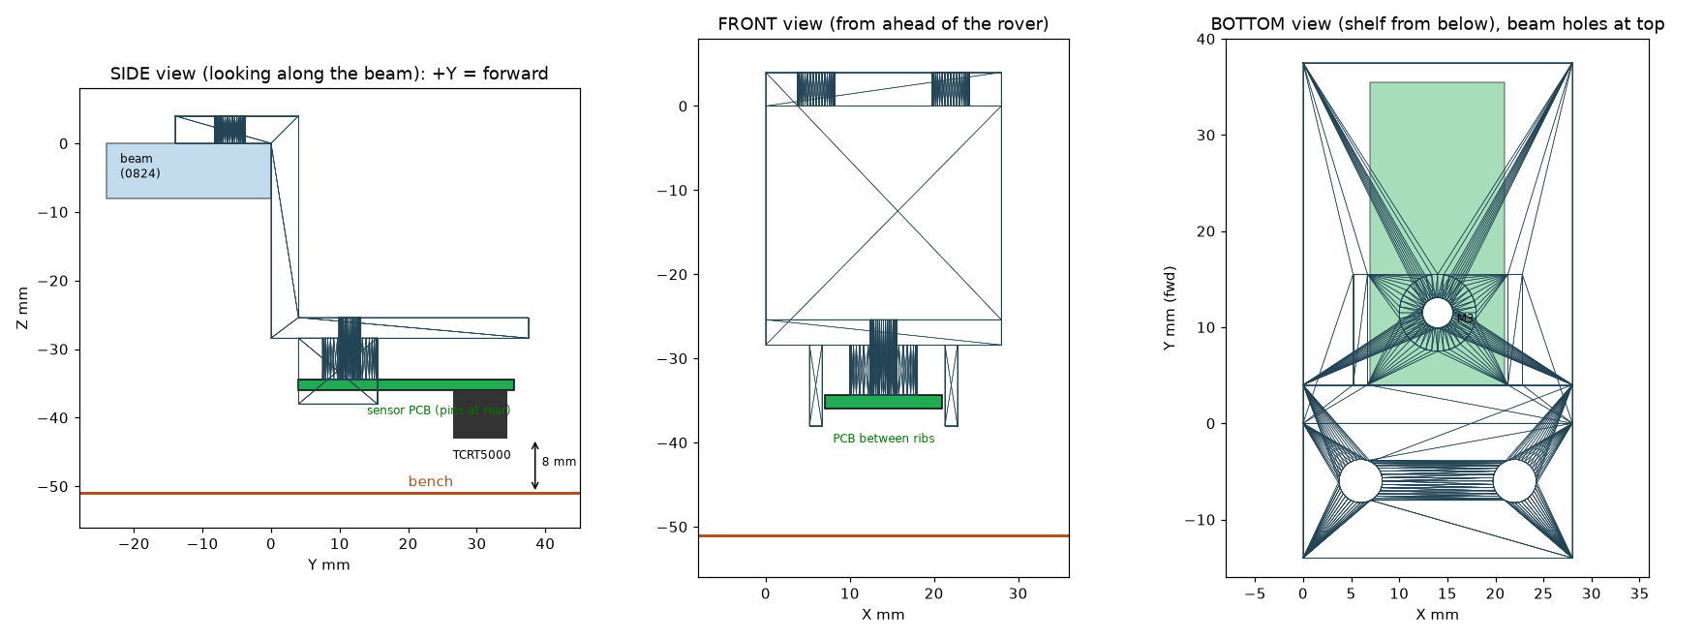
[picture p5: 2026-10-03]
hardware/cliff-mount-drawing.png

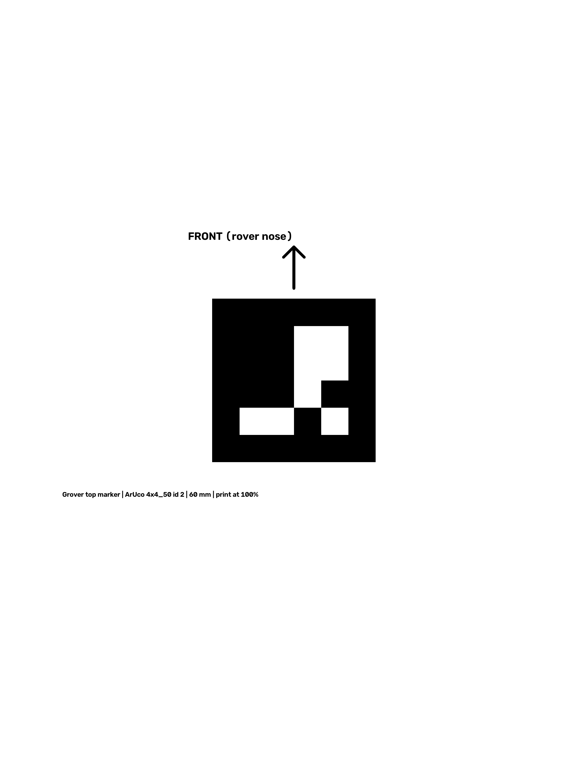
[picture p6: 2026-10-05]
hardware/markers/aruco_4x4_50_id2_60mm.png

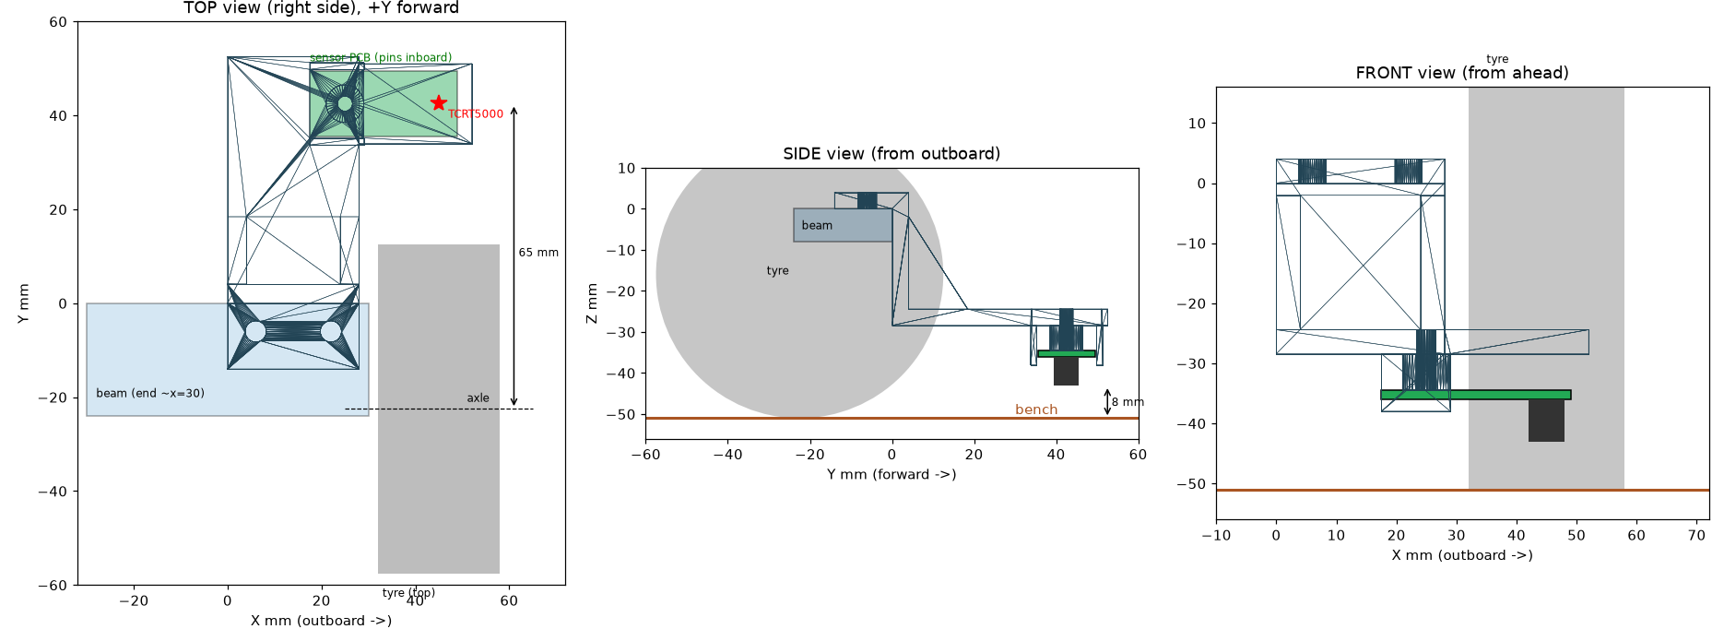
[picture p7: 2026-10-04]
hardware/cliff-mount-v4-drawing.png

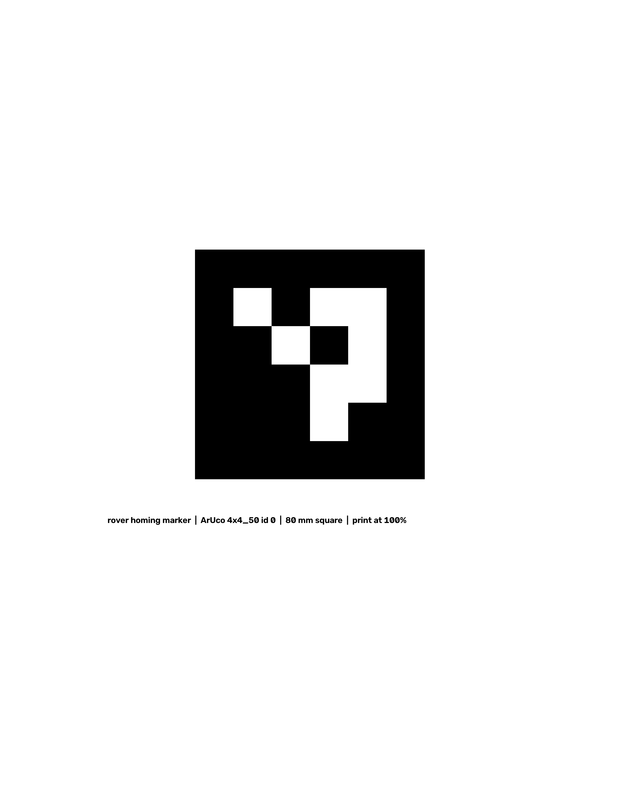
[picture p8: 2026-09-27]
hardware/markers/aruco_4x4_50_id0_80mm.png

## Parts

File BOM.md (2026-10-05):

# Bill of Materials & Shopping List

## Budget policy

If Enoch already has a part in inventory, he supplies it. Anything else this
project needs comes out of a standing **$100 budget** that Claude tracks here.
This budget only covers purchases Claude actually asks for - if Enoch chooses
to just go buy something himself (as with the IR sensors below), it doesn't
draw against it. Update the running total every time something *is* drawn
from it - don't let it go stale.

**Budget spent so far: $3.29 — remaining: $96.71** (as of 2026-10-05)

| Date | Item | Cost |
|---|---|---|
| 2026-09-29 | GH1.25-to-Dupont 2.54 pre-crimped cable + connector kit (Amazon B087N4GY8Z) - Enoch bought it for inventory; Grover's share (one 4-pin TFMini lead) prorated by Enoch | $0.40 |
| 2026-09-29 | 3S 40A BMS protection/balance board (Gebildet, Amazon B0G6JQ8ZFN) - Enoch bought a 3-pack for $8.66 for inventory; one is Grover's, so 1/3 is charged here | $2.89 |
| 2026-09-28 | ~~Eufy RoboVac 12 replacement battery (Amazon)~~ ordered at $18.10, then cancelled the same evening - the vacuum's bottom power switch was off, the pack is fine | $0.00 |

## Bill of Materials - Grover (as built, 2026-10-05)

All from Enoch's inventory unless the Source column says otherwise.

| Component | Qty | Role | Source | Status |
|---|---|---|---|---|
| Makeblock Starter Robot Kit, **trike** (two driven wheels + trailing caster; tank until 2026-09-29) | 1 | Chassis and two DC gear motors | Inventory | Installed |
| ESP32 devkit (WROOM-32D, 38-pin) - `rover32` | 1 | Spinal cord (ESPHome): enables GPIO16/17, direction GPIO18/19/22/23, cliff GPIO35/32, TFMini I2C GPIO25/26, battery GPIO34 | Inventory (was the Eufy IR node's board) | Installed 2026-10-03 |
| L298N dual H-bridge | 1 | Motor driver | Inventory | Installed |
| 18650 Li-ion cells | 3 (3S) | Power, 12.6 V full / ~9 V empty | Inventory | Installed; one weak set retired 09-29, one bad cell found 10-04 - charge the set together and full |
| LM2596 buck, set to 5.2 V | 1 | 5 V for the ESP32 (VIN), the camera (spliced micro-USB) and the TFMini | Inventory | Installed |
| Resistors 100k + 27k | 1 each | Battery divider into GPIO34 (x4.664, calibrated 10-03 against a meter) | Inventory | Installed |
| Benewake TFMini (SparkFun SEN-14786) | 1 | Forward LiDAR: obstacle stop 50 cm, range for homing | Inventory | Installed on the printed bracket; direct GH1.25 lead, 5 V |
| GH1.25-to-Dupont lead (kit B087N4GY8Z) | 1 | TFMini direct connection (replaced the Qwiic boost chain and LD33V) | $0.40 prorated (budget) | Installed |
| TCRT5000 cliff modules (HW-870) | 2 | Front cliff detection, DO at 3.3 V | Enoch's purchase (not budget) | Installed on v4 mounts |
| TTGO T-Camera (`redcam`) | 1 | Rover camera | Inventory | Installed (printed cradle + adapter strip) |
| Printed parts (PETG): camera cradle, adapter strip, TFMini bracket, cliff mounts v4 (L+R) | - | see `hardware/README.md` | $0 | Installed |
| Printed caster skid (`hardware/caster-skid.scad`) + M5 bolt 25-30 mm + nut | 1 | Replaces the swivel caster (it yaws the rear on stops) | $0 | Staged to print |
| 3S BMS 40A board (1 of a 3-pack, B0G6JQ8ZFN) | 1 | Per-cell protection + balancing | $2.89 prorated (budget) | In hand, install deferred |
| Bench cameras: `camv3` (Thingino), `fishcam` (Wyze Pan v2, Thingino PTZ) | 2 | Watch the bench from behind and head-on | Inventory | Installed |

Retired: Wemos D1 Mini (now the bench IR test node `eufy-ir8266`), MCP23008
expander, LD33V regulator (TFMini now on 5 V directly), the Qwiic adapter
chain.

## Bill of Materials - the Eufy (house chassis)

| Component | Qty | Role | Source | Status |
|---|---|---|---|---|
| Eufy RoboVac 12 + dock + remote | 1 | House chassis: its own docking, charging, cliff and bumper behaviour | Inventory | Working |
| TTGO T-Camera V1.7 (`blackcam`) | 1 | Lid board: camera + IR (IO22), powered from its header 5 V | Inventory (spare) | Flashed and proven 2026-10-04; lid mounting/power next |
| 940 nm IR LED + NPN (2N2222/2N3904) + 1k base + 33R | 1 set | IR driver, ~105 mA, 2 m range | Inventory (LED/receiver kit) | Wired on blackcam |
| VS1838B 38 kHz receiver + Wemos D1 Mini (`eufy-ir8266`) | 1 | Bench tool for capturing/decoding remote frames | Inventory | In use |
| ESP32-C3 Super Mini (`eufy-ir-c3` config) | 1 | Spare IR node if needed | Inventory | Config ready, not flashed |

(The Roomba plan - mini-DIN plug, level shifter - is shelved; the Roomba was gone.)

## How to keep this current

- When a shopping-list item is actually acquired, move it into the BOM table
  with `Installed` status and log its real cost against the budget line above.
- When a part is swapped or removed, update its BOM row rather than deleting
  history - note what replaced it and why (and cross-reference the
  [journal](JOURNAL.md) entry that made the call).
- Anything that shows up in `rover.yaml` referencing a pin/sensor that isn't
  in this table yet is a bug in this file - fix it in the same change.

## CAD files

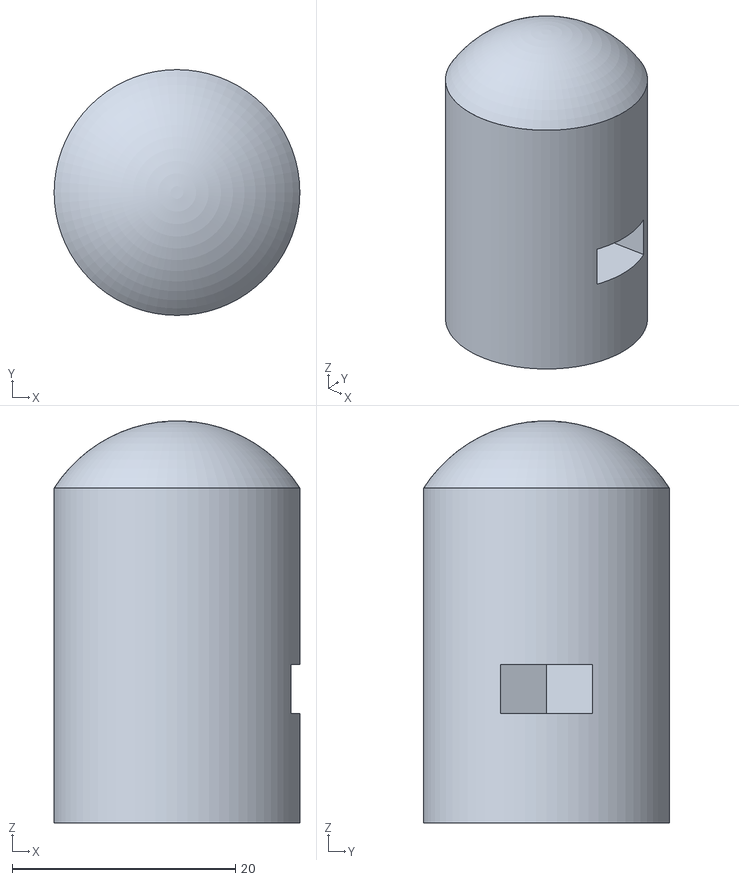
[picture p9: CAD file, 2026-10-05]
hardware/caster-skid.stl
22.0 x 22.0 x 36.0

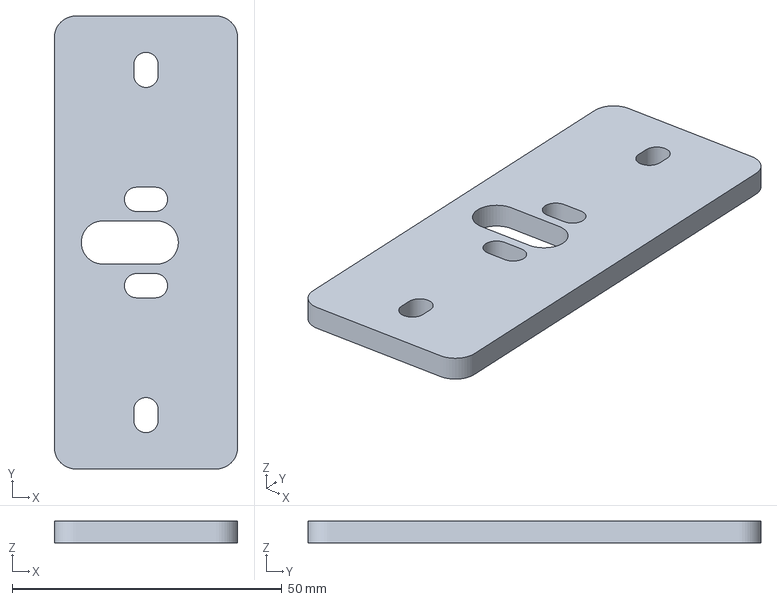
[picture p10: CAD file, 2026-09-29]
hardware/prints/camera-strip_v1.3mf
34.0 x 84.0 x 4.00 mm

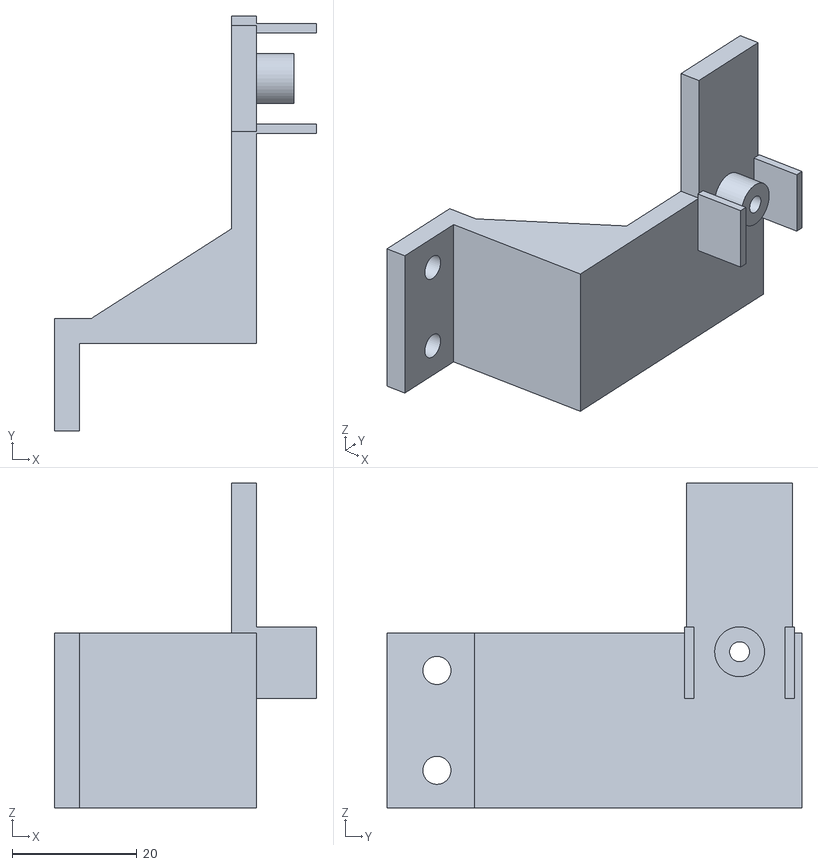
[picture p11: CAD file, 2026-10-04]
hardware/cliff-mount-right.stl
42.0 x 66.5 x 52.0

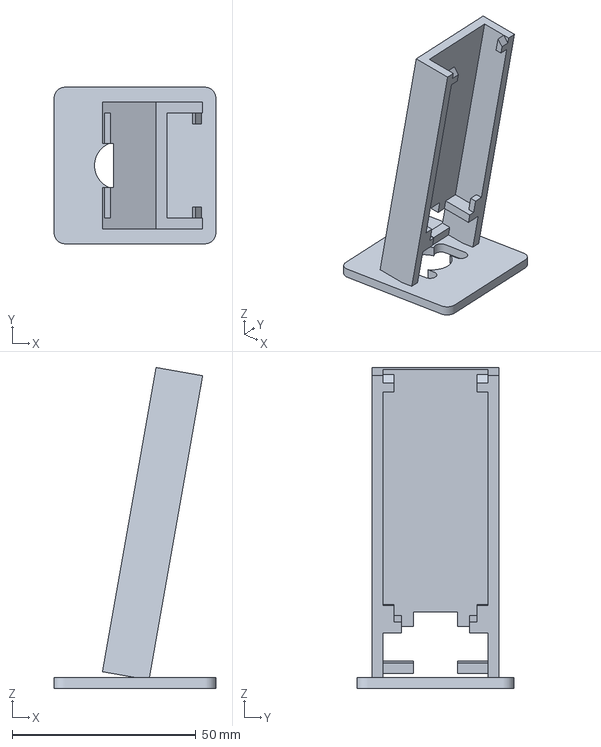
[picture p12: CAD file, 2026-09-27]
hardware/prints/camera-mount_v5.3mf
44.0 x 42.6 x 87.3 mm

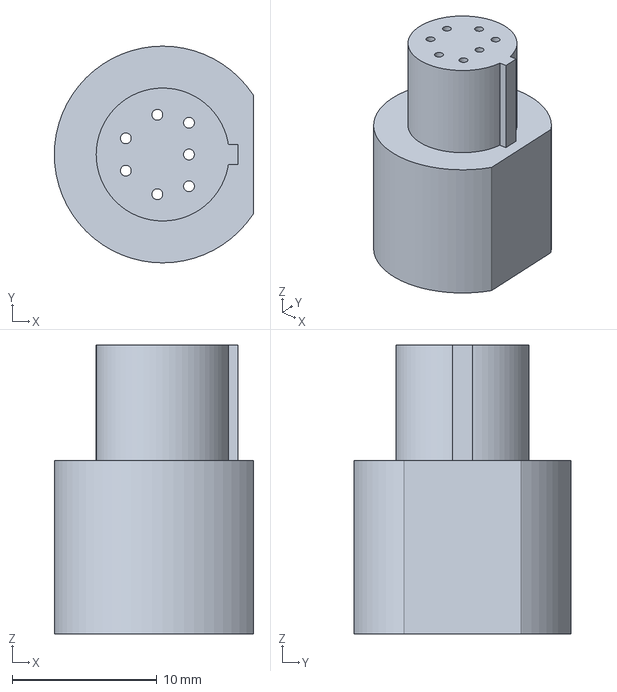
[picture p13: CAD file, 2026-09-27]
hardware/prints/roomba-minidin-plug_v1_TESTFIT.3mf
13.8 x 15.0 x 20.0 mm

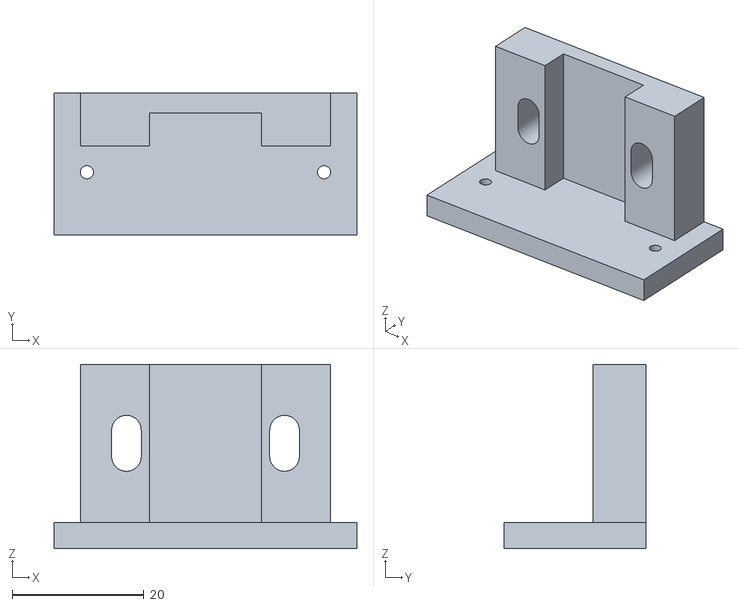
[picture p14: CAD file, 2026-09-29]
hardware/tfmini-bracket.stl
46.0 x 21.5 x 28.0

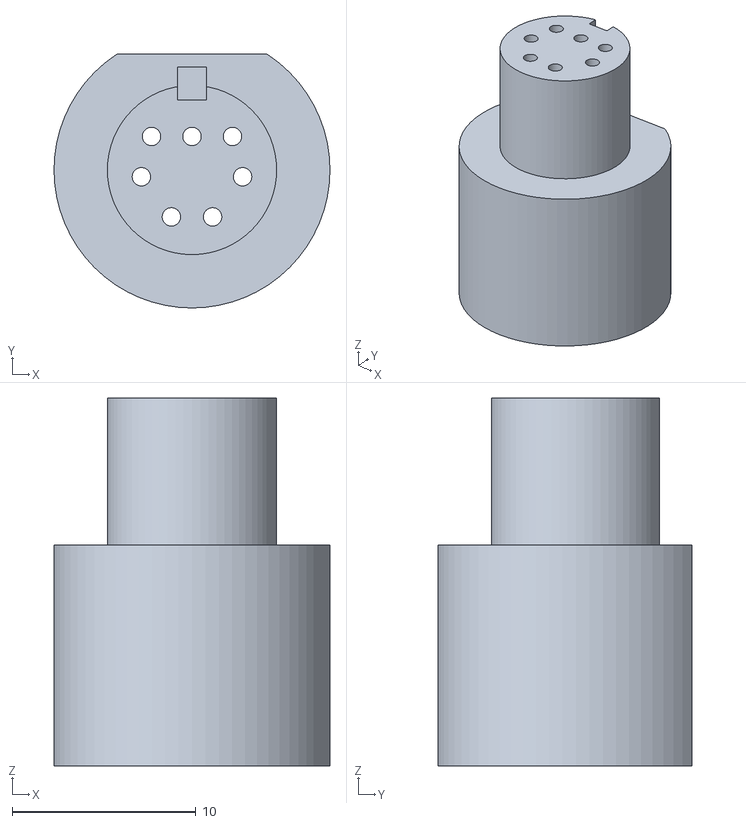
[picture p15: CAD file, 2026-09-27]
hardware/roomba-minidin-plug.stl
15.0 x 13.8 x 20.0

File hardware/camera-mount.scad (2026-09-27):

// Camera mount: holds a TTGO T-Camera (ESP32-WROVER-B, OV2640 V1.7) upright on
// the rover's Makeblock plate, camera/PIR/OLED facing forward, tilted down.
//
// Design: a raised cradle on a pedestal. Two side rails grip the PCB's long
// edges in slots; the front is fully open (nothing in front of the lens, PIR,
// or OLED). The board's BOTTOM edge carries the micro-USB port and the 5-pin
// connector, so the cradle floats `usb_clear` mm above the base with an open
// gap underneath: the board rests on two small corner tabs, the USB plug hangs
// through the gap, and the cable exits rearward through a window in the
// pedestal. The base bolts to the Makeblock plate with M4 hardware on the
// plate's 8mm hole grid.
//
// Render:  openscad -o camera-mount.stl camera-mount.scad
// Print:   base down, no brim, tree supports on auto (see hardware/README.md)
//
// !! PLACEHOLDER DIMENSIONS - the pcb_* and usb_* values are estimates and
// !! MUST be replaced with caliper measurements of the real board first.

// ---- Board (MEASURE THESE) --------------------------------------------------
pcb_w     = 28.0;   // PCB width  (bottom/top edge), mm      <- measure
pcb_l     = 68.0;   // PCB length (side edge, bottom->top), mm <- measure
pcb_t     = 1.27;    // PCB thickness, mm                     <- measure
comp_back = 6.0;    // tallest component on the BACK face, mm <- measure
usb_x     = 0.0;    // micro-USB centre offset from the board's centreline
                    // along the bottom edge (+ = right, viewed from the
                    // lens side), mm                        <- measure
usb_plug_w = 12.0;  // width of the micro-USB PLUG overmold (not the socket)
usb_plug_t = 8.0;   // thickness of the plug overmold (front-to-back)
usb_clear  = 16.0;  // gap under the board for the plug body (cable goes straight down)
cable_slot_w = 13.0; // base pass-through for the cable, wide enough for the plug overmold
cable_slot_l = 16.0; // ... and long enough to cover the 10-degree tilt offset

// ---- Mount geometry --------------------------------------------------------
wall      = 3.0;    // rail/backplate/pedestal thickness
clear     = 0.3;    // slot clearance around the PCB (PETG shrinks a little)
rail_d    = 3.0;    // how deep each rail overlaps the PCB edge
lip       = 2.0;    // front lip height that stops the board sliding forward
lip_len   = 4.5;    // length of each corner lip along the board edge (must stay
                    // inside the component-free zones at both board ends)
tab_w     = 5.0;    // width of the two bottom corner tabs the board rests on
tilt      = 10;     // degrees the camera looks DOWN from horizontal
base_l    = 44;     // base plate length (along the rover's travel axis)
base_t    = 3.0;    // base plate thickness

inner_w  = pcb_w + 2*clear;
inner_t  = pcb_t + 2*clear;
outer_w  = inner_w + 2*wall;
depth    = comp_back + wall + inner_t + lip;   // cradle front-to-back
base_w   = outer_w + 8;

// ---- Makeblock plate interface ---------------------------------------------
mb_pitch  = 8;      // Makeblock hole grid, mm
m4_hole   = 4.4;    // M4 clearance
slot_len  = 8;      // slots let the mount sit on either 8mm or 16mm centres

$fn = 48;

module base() {
  difference() {
    linear_extrude(base_t)
      offset(r=3) offset(delta=-3) square([base_w, base_l], center=true);
    for (x = [-mb_pitch, mb_pitch])
      hull() for (y = [-slot_len/2, slot_len/2])
        translate([x, y, -1]) cylinder(d=m4_hole, h=base_t+2);
    // cable pass-through: the USB lead runs straight down from the board's
    // bottom edge, in line with the board, through here and then through the
    // Makeblock plate's own hole on the centreline below. Centred slightly
    // aft (+y) because the 10-degree lean puts the bottom edge behind the pivot.
    hull() for (y = [3 - (cable_slot_l - cable_slot_w)/2, 3 + (cable_slot_l - cable_slot_w)/2])
      translate([usb_x, y, -1]) cylinder(d=cable_slot_w, h=base_t+2);
  }
}

// Built "flat": board face toward +Z, board length along +Y, bottom edge at
// y = 0. The pedestal extends below y = 0 down to y = -usb_clear.
module cradle_flat() {
  z0 = -(comp_back + wall);            // back face of the back plate
  h  = pcb_l;
  difference() {
    union() {
      // back plate, running from the pedestal foot up to the top of the board
      translate([-outer_w/2, -usb_clear, z0]) cube([outer_w, usb_clear + h, wall]);
      // side rails (full board length) and their pedestal legs below
      for (s = [-1, 1])
        translate([s*(inner_w/2) - (s<0 ? wall : 0), -usb_clear, z0])
          cube([wall, usb_clear + h, depth]);
      // front lips at the FOUR CORNERS only. The board's front face is busy
      // right up to its edges (buttons at the edges ~8 mm up, OLED glass
      // nearly full-width near the top), so full-length lips would collide;
      // only the bottom ~8 mm and top ~6 mm are component-free. Insert the
      // board bottom-first under the lower lips, then tilt the top back past
      // the chamfered upper lips.
      for (s = [-1, 1]) {
        x0 = (s > 0) ? inner_w/2 - rail_d : -inner_w/2;
        translate([x0, 0, inner_t]) cube([rail_d, lip_len, lip]);            // bottom corners
        translate([x0, h - lip_len, inner_t])                                  // top corners, chamfered
          hull() {
            cube([rail_d, lip_len, 0.01]);
            translate([0, 0, lip]) cube([rail_d, lip_len - lip, 0.01]);
          }
      }
      // two bottom corner tabs INSIDE the rails, under the board's bottom
      // edge, so the board actually rests on them (same v3 fix)
      for (s = [-1, 1])
        translate([s > 0 ? inner_w/2 - tab_w : -inner_w/2, -wall, z0])
          cube([tab_w, wall, depth]);
    }
    // the USB plug hangs through the gap between the tabs; make sure the gap
    // is at least the plug width, centred on the port
    translate([usb_x - usb_plug_w/2, -usb_clear - 1, z0 - 1])
      cube([usb_plug_w, usb_clear + 2, depth + 2]);
    // cable exit window through the back plate, below the board
    translate([-outer_w/2 + wall, -usb_clear + wall, z0 - 1])
      cube([outer_w - 2*wall, usb_clear - 2*wall, wall + 2]);
  }
}

module mount() {
  base();
  // Stand the cradle up: 90 deg about X points the board face along -Y
  // (forward) with the board length up +Z; more than 90 leans the top
  // forward so the lens looks DOWN by `tilt`. The pedestal foot (y = -usb_clear
  // in flat coords) lands on the base.
  translate([0, 0, base_t])
    rotate([90 + tilt, 0, 0])
      translate([0, usb_clear, 0])
        cradle_flat();
}

mount();

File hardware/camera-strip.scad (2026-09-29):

// Camera adapter strip: bolts the v5 camera cradle (camera-mount.scad) rigidly
// to the rover chassis. The cradle used to sit loose on the plate and shifted
// on every jerky pulse, which corrupted the marker bearings.
//
// The strip spans the two front M4 standoffs on the chassis plate (Makeblock
// grid, 64 mm centre-to-centre, 30 mm tall) and bolts down into their tops.
// On top it presents the cradle's own hole pattern (M4 slots on 8 mm
// centres) so the cradle bolts to the strip with two M4 screws and nuts.
// The camera lead drops through a narrow slot under the cradle - plug the
// camera in and seat it in the cradle first, then bolt the cradle down.
//
// Orientation: the strip runs LEFT-RIGHT across the rover (X); Y is the
// travel axis, +Y forward. Print flat, no supports, no brim.
//
// Render:  openscad -o camera-strip.stl camera-strip.scad

// ---- Chassis (measured by Enoch, 2026-09-29) --------------------------------
post_cc     = 64.0;   // standoff centre-to-centre; measured 68.5 mm across the
                      // outer edges of the M4 holes, i.e. 8 Makeblock grid units
post_slot_l = 6.5;    // slot length along X so 63-66 mm c-c all fit
m4_hole     = 4.5;    // M4 clearance, slightly oversized on purpose (Enoch's ask)

// ---- Cradle interface (must match camera-mount.scad) -----------------------
mb_pitch    = 8;      // cradle slots sit at x = +/-8
cradle_slot = 8;      // cradle slot length along Y - mirrored here for +/-4 mm adjust
cable_w     = 8.0;    // cable-only pass-through (the plug goes in before bolting)
cable_l     = 18.0;
cable_y     = 3.0;    // same aft offset as the cradle's cable slot

// ---- Strip ------------------------------------------------------------------
strip_l = post_cc + 20;   // 84 mm: 10 mm of material beyond each post
strip_w = 34;
strip_t = 4;
corner  = 4;

$fn = 48;

module slot(len, d, along = "y") {
  a = (along == "x") ? [1, 0] : [0, 1];
  hull() for (s = [-1, 1]) translate([s * a[0] * (len - d) / 2, s * a[1] * (len - d) / 2, -1])
    cylinder(d = d, h = strip_t + 2);
}

module strip() {
  difference() {
    linear_extrude(strip_t)
      offset(r = corner) offset(delta = -corner) square([strip_l, strip_w], center = true);
    // standoff bolts, slotted along X to absorb the c-c uncertainty
    for (x = [-post_cc / 2, post_cc / 2]) translate([x, 0, 0]) slot(post_slot_l, m4_hole, "x");
    // cradle bolts, slotted along Y like the cradle's own base
    for (x = [-mb_pitch, mb_pitch]) translate([x, 0, 0]) slot(cradle_slot, m4_hole, "y");
    // camera lead
    translate([0, cable_y, 0]) slot(cable_l, cable_w, "y");
  }
}

strip();

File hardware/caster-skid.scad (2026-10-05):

// Caster skid: replaces Grover's swivel caster with a fixed, domed PETG
// skid. The swivel caster twisted the rear on stops (2026-10-05: with the
// caster zip-tied straight, Grover stopped square; free, it yawed 20-30 deg).
// A round skid is rotationally symmetric, so the single mounting bolt can't
// "steer" it.
//
// Mounting: the caster hung from one threaded stem through a 5.5 mm hole
// in the blue Makeblock block, bracket underside 36 mm above the bench
// (Enoch's measurements). Here: an M5 bolt goes down through that hole and
// into a captive M5 nut, slid into the skid through a side slot.
//
// Print: on its flat TOP face, dome up. The nut slot's roof is a ~9 mm
// bridge, which PETG handles without supports. No brim.
//
// Render:  openscad -o caster-skid.stl caster-skid.scad

height    = 36;     // bracket underside to bench (Enoch, 2026-10-05)
dia       = 22;     // puck diameter
dome_h    = 6;      // spherical-cap height of the sliding face
bolt_d    = 5.5;    // M5 clearance
nut_af    = 8.2;    // M5 nut across flats + clearance
nut_t     = 4.4;    // M5 nut thickness + clearance
nut_z     = 12;     // nut pocket depth below the top face
$fn = 72;

// spherical cap radius for a cap of height dome_h on a base of radius dia/2
cap_r = (pow(dia / 2, 2) + pow(dome_h, 2)) / (2 * dome_h);

module skid() {
  difference() {
    union() {
      // body: from the dome base up to the top face
      translate([0, 0, dome_h]) cylinder(d = dia, h = height - dome_h);
      // dome (sliding face) at the bottom, z = 0 .. dome_h
      intersection() {
        translate([0, 0, cap_r]) sphere(r = cap_r);
        cylinder(d = dia, h = dome_h + 0.01);
      }
    }
    // bolt hole from the top down past the nut
    translate([0, 0, height - nut_z - 8]) cylinder(d = bolt_d, h = nut_z + 9);
    // captive nut pocket, open to one side
    translate([0, 0, height - nut_z - nut_t / 2])
      hull() {
        cylinder(d = nut_af / cos(30), h = nut_t, $fn = 6);
        translate([dia, 0, 0]) cylinder(d = nut_af / cos(30), h = nut_t, $fn = 6);
      }
  }
}

// print orientation: top face down
translate([0, 0, height]) rotate([180, 0, 0]) skid();

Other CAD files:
hardware/cliff-mount-left.stl
hardware/camera-mount.stl
hardware/cliff-mount.scad
hardware/roomba-minidin-plug.scad
hardware/tfmini-bracket.scad

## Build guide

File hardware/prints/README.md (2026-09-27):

# Sliced prints

Output of `hardware/slicing/slice.sh` (Sidewinder X4 Plus, 0.20mm, PETG, no
brim, tree supports on auto). The `.3mf` opens in OrcaSlicer for inspection;
the `.gcode` is what goes to the printer.

| File | Source | Est. time / filament | Notes |
|---|---|---|---|
| `camera-mount_v5.*` | `hardware/camera-mount.scad` with measured board dims (28.0 x 68.0 x 1.27 mm, 6 mm rear components) and a straight-down cable slot in the base; v4 moved the tabs and lips inward; v5 shortens the lips to the four corners because buttons and OLED reach the board edges | see G-code header | Reprint candidate - confirm the component-free zones first. |
| `roomba-minidin-plug_v1_TESTFIT.*` | `hardware/roomba-minidin-plug.scad` | see G-code header | **Test-fit print** for the Roomba port plug - check insert fit, key, and wire holes, then tune the parameters and re-slice. |

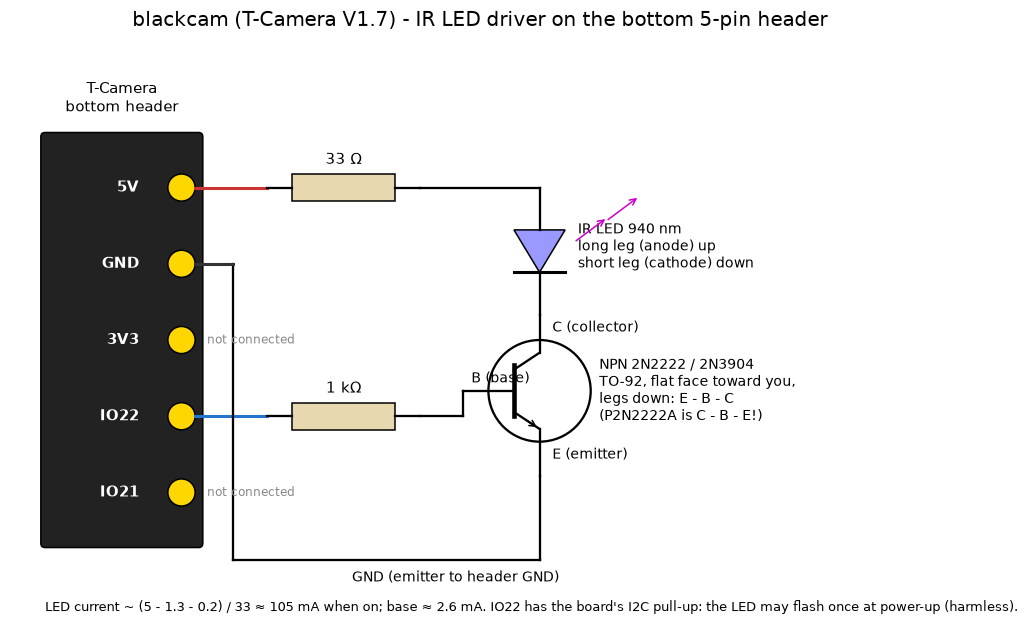
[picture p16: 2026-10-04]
hardware/blackcam-ir-wiring.png

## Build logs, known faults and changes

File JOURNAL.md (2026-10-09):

# Project Journal

This is the running log for the rover project: what changed, why, who decided
it, and which model did the work. It exists so that:

- Anyone (Enoch, a future Claude session, a different model entirely) can pick
  up exactly where things left off without re-deriving context.
- It's visible how much of this build is **Claude-driven** (identified,
  designed, or implemented without being asked for that specific thing) versus
  **Enoch-decided** (explicit direction, approval, or a choice only he could
  make - hardware in hand, budget, mission scope, etc.).

Each entry: date, model used, a summary of the guidance/instructions given
that session, what actually happened, and a Claude-driven/Enoch-decided
breakdown of the notable decisions. Newest entry on top.

---

## Current status (as of the latest entry below)

**Where things stand, 2026-10-05:**

- **Two robots, one brain.** **Grover** (Makeblock trike, bench platform)
  and a **Eufy RoboVac 12** (the house chassis, driven over IR). The
  brain (`brain/`, MCP server `rover-brain`) drives Grover; the Eufy is
  commanded through its lid board, `blackcam`.
- **Grover's spinal cord is an ESP32** (`rover32`, ESPHome) since
  2026-10-03 - no I/O expander, the TFMini alone on its own I2C bus.
  Guards in firmware: command watchdog, disconnect-stop, low-battery
  refusal (fixed today - see the week in review), cliff refusal, TFMini
  obstacle stop at 35 cm (incl. "was close, now too close to measure"),
  100 ms kick start, left-motor trim +6 %.
- **Sensors on Grover:** TFMini forward LiDAR (mounted, calibrated to
  1 cm), two TCRT5000 cliff sensors (v4 mounts put them on each tyre's
  centreline 65 mm ahead of the axle), rover camera `redcam`, plus two
  bench cameras (`camv3` behind, `fishcam` PTZ head-on).
- **Visual homing works** (`home_to_marker`, unattended arrivals to
  ~9-21 cm of an ArUco marker).
- **Grover drove through the house** on 10/04 - dining room, foyer,
  living room, to the kitchen doorway (~12-14 m) - and stopped itself at
  the edge of anything it couldn't clear (a dog, people, sun glare).
- **The Eufy is under our control.** Its IR protocol is decoded (the
  remote stamps the time into every command); `blackcam` (a T-Camera on
  the lid: camera + IR LED driver) drove it off the dock and sent it home.
- **Open:** a recurring hard swing at the start of some Grover pulses
  (kick start + battery-guard fix are the current suspects' remedies,
  untested); edge-stop test with the v4 cliff mounts; brain as a hosted
  service; Eufy battery/charging telemetry; BMS boards in hand, deferred.
- **Swing diagnosis (10/05, late):** battery-guard fix verified
  (`battery_ok=1`); TFMini guard verified (refuses forward; raised to
  50 cm and polled at 50 ms after a kicked pulse ended 15 cm from a box).
  Enoch saw the drift happen *after* a pulse stops, "like the right wheel
  freewheeling". Brake on vs off: both still turned ~20-30 deg on the
  stopping pulse; **with the swivel caster zip-tied straight, Grover
  stopped square**. Leading cause: the swivel caster twisting the rear on
  stops. Fix: Makeblock ball caster if in inventory, else a printed PETG
  fixed skid in the caster's holes (needs hole spacing and mount height). No ball caster in inventory, so: `hardware/caster-skid.scad` - a domed
  22 mm PETG puck, 36 mm tall, on one M5 bolt with a captive nut; staged.
  Also answered Enoch on the BMS: balance pads are taps only (no cutting
  between cells); the only re-route is the pack negative, which now goes
  to the board's 0V/B- while the load's negative moves to P-.
- **fishcam remounted overhead** (Enoch), looking straight down the bench -
  now the brain's `bench` camera; camv3 moves to the Eufy as its lid
  camera (Enoch's choice; the ESP32-C3 takes the IR job). First overhead
  test: two straight pulses, then a 20-25 deg yaw exactly where the front
  wheels met the **bench hatch's lip** (Enoch confirmed a slight lip; the
  black T-shape Claude first called its hinge is his solder fan).
  Revised picture of the swings: the swivel caster lets the rear swing,
  and bumps/seams (the hatch lip) or the stop transient start it. Fixes:
  the caster skid (printing) and a no-go/cross-square rule for the hatch
  in CLAUDE.md. Next: an ArUco marker taped on Grover's top so the
  overhead camera measures heading exactly (colour-segmenting the thin
  blue beam wasn't reliable). A second overhead run in the lane *above* the hatch (Enoch moved
  Grover there) still pivoted ~90 deg left over two pulses, and a kicked
  0.3 s pulse now covers ~45 cm. So the hatch lip is a trigger, not the
  cause; the free swivel caster remains the prime suspect (skid printed,
  to fit), with the kick start's extra speed feeding it - trim the kick
  (50 ms or 85 %) after the skid test.
- **Pause: Enoch travelling ~2 weeks from 10/05.** Hardware state left:
  caster skid printing (fit when back); Grover should be powered off
  (the firmware guard only stops driving - idle draw still drains the
  pack; no BMS fitted yet); Eufy on its dock; blackcam powered from the
  bench. Pick-up list on return: (1) fit the skid, overhead lane test;
  (2) trim the kick start; (3) ArUco marker on Grover's top for overhead
  heading; (4) cliff edge-stop test; (5) Eufy lid plate - needs a
  top-down photo with a ruler, the IR receiver location (tape test),
  camv3 off the bench, the C3 IR node flashed, a power bank.
- **Software while Enoch is away** (his go-ahead; deploy the brain where
  homelab-helper recommends). Done 10/05: `locate` (overhead pose from
  ArUco id 2 taped on Grover's top - page generated; self-test within
  0.2 deg; live frame finds the homing marker), `eufy` tool + `eufy`
  camera (service lookup verified; no command sent - nobody home to
  watch the vacuum), Streamable HTTP mode + Dockerfile (image builds,
  initialize handshake OK), and a fix to `install-brain.sh` (a comment
  mid-line meant fresh installs got only `mcp`). Placement request sent
  to the homelab-helper session; camv3-to-Eufy note sent too.
- **The brain is hosted** (Enoch: deploy where homelab-helper recommends).
  Its answer: own Argo CD app mirroring unifi-network-mcp, namespace
  `rover-brain`, ghcr image, Traefik basic auth + cert-manager TLS,
  SealedSecrets. Added proxy host settings to the server and a GHCR build
  workflow (tag v0.1.0 -> public `ghcr.io/moellere/rover:0.1.0`), sealed
  the credentials and basic-auth users with kubeseal, validated with
  kubeconform (9/9), merged moellere/argocd#151. Live: pod Running, cert
  Ready, external-dns record, 401 without auth / 200 with; from the pod
  it reaches fishcam, blackcam and blackcam's ESPHome API. `claude mcp`
  entry `rover-brain` now points at the hosted endpoint
  (`rover-brain-local` keeps the stdio copy). homelab-helper also moved
  print-warden's printer-camera plan off camv3 (fishcam as an overview).
- **Eufy motion characterised** (Enoch: "I believe the movements will be
  fixed nudges... validate now"). Garage floor, docked, lights on via HA;
  one IR command each, blackcam frames at 1 s and 4 s. Every command is a
  **fixed nudge, finished within 1 s**: Backward ~5-10 cm off the dock,
  Left a ~30-45 deg rotation, Right roughly undid it, Forward drove it
  straight back onto the dock contacts (charging LED). Home wasn't needed.
  Rough numbers from a camera on the lid itself - a calibrated run with
  the overhead camera and the id-2 marker is still to do. Consequence: the
  disconnect-stop watchdog planned for blackcam would protect nothing (no
  command leaves the vacuum moving; Start/Stop is a toggle that a blind
  watchdog would turn *on*), so instead the IR queue is capped at one
  sending + one waiting, so a vision loop can't have a stale backlog fire
  late. Navigation plan: brain-side step-and-measure loop (nudge, frame,
  re-plan), IMU on the lid board only if turns can be interrupted.
- **Can a nudge be cut short?** (Enoch asked how a gyro helps if a turn is
  a fixed 30-45 deg.) Test: Left, then Start/Stop 300 ms later on the same
  API connection. The turn completed to about the baseline angle (in
  progress at 0.5 s, done by 1 s), and Start/Stop neither stopped it nor
  started a cleaning cycle - ignored mid-nudge. Read by eye: ORB matching
  on the glossy lid gave too few inliers; the id-2 marker on the lid would
  make this exact. Not yet tried: interrupting with the opposite turn.
  Home from ~10 cm off the dock, rotated: docked and charging within 30 s.
  Working conclusion: turns are fixed ~30 deg quanta; the gyro is shelved
  (it could only measure them), navigation is nudge-and-look with the
  camera correcting, and finer control would mean driving the wheel
  motors directly - Enoch's call.
- **The Eufy escaped to the yard twice (10/05-10/08) - a schedule, probably
  shifted by our frames.** Enoch found it outside after the garage door was
  left open. Checked: no Eufy command from any Claude session after the
  supervised 10/04 tests, none from the hosted brain, no HA button
  presses. But blackcam's PIR (facing the dock) fired at 6:00:27 PM,
  6:01:56 PM and 6:00:20 PM on 10/05-10/07, uncorrelated with door events
  (the big door was open noon-8 PM those days): a daily scheduled clean.
  Likely mechanism: our frames stamp the hour as 12-h (`hh % 12`), which
  sets the vacuum's clock with no AM/PM, so a 6:00 AM schedule could now
  fire at 6:00 PM. Nest clips aren't reachable (HA's Nest event cache is
  empty). **Hold: no Eufy IR commands** until the hour encoding is checked
  against the real remote's frames and the schedule is cleared.

Standing project rules live in [CLAUDE.md](CLAUDE.md) - read that first;
decisions and their reasoning are in the dated entries below. The
week-in-review entry right below summarises 09-29 .. 10-05; the dated
notes after it carry the detail (a few were appended out of order).

---

## 2026-09-29 .. 10-05 - Week in review: trike, TFMini, ESP32, cliff sensors, the house, the Eufy

**Models:** Claude Fable 5.1 through 10/04 afternoon, then **Claude Opus
5.5** (Fable's usage limit - the fallback CLAUDE.md names). Same
conversation throughout; the handoff was invisible to the work.

### Guidance from Enoch this week
- Grover named (09/29). "You tell me what you want to do next" - Claude
  picks milestones and moves through them without asking (recorded in
  CLAUDE.md); physical work and purchases still go through Enoch.
- Device permissions widened: the spinal cord, redcam, camv3, fishcam,
  the Eufy IR node, blackcam and Grover's ESP32 are Claude's to flash.
- Hardware realities he supplied: inventory (TFMini, ESP32 devkits,
  C3/S3/C6 minis, 940 nm LED/receiver kit, NPN transistors, a spare
  T-Camera that powers from its header), measurements (beam heights,
  wheel diameter, sensor board), and fixes (bad battery cell, swapped
  wires, a 3.3 V "GND", mis-wired receivers).
- Ground rules for the house run: no fall hazard; reversing/pivoting OK;
  "Taters" (the dog) will ignore you or bark; he watched the last stretch.

### What happened (threads, roughly in order)
1. **Trike + homing (09/29).** Tank tracks skidded on pivots, so the kit
   was rebuilt as a two-wheel trike with a trailing caster. Visual homing
   (closed loop: look, pivot toward the marker, step, re-look) arrived
   unattended three times. A reverse test put a wheel over the bench
   edge (caster flip drags the rear); new rule: reverse only in single
   short pulses, bench camera checked first.
2. **Brake-on-stop A/B.** Built a dynamic brake into every stop path;
   measured with the marker as a ruler - no measurable effect on short
   pulses, and it correlated with camera dropouts, so it became a switch
   that boots off.
3. **Battery.** A pack that sagged 2 V in 25 min idle was weak cells (not
   load) - proven by an idle drain log. 3S BMS boards bought for
   inventory (pad map recorded; deferred). One more bad cell found 10/04.
4. **Fishcam joined** as a head-on PTZ view; marker detection gained a
   CLAHE contrast retry for backlit frames.
5. **TFMini.** Bracket designed and printed; power plan reworked (Enoch
   spotted 5 V -> 3.3 V -> boost -> 5 V); direct GH1.25 lead. Bring-up was
   hard: every I2C read NACKed and the sensor wedged SCL low, taking the
   motor expander with it. Fix: repeated-start reads, 100 kHz, 20 ms
   clock-stretch limit. Calibrated (78 vs 77 cm); 35 cm obstacle guard.
6. **ESP32 spinal cord (`rover32`).** Because a wedged TFMini froze the
   motor controller, the spinal cord moved to an ESP32 devkit (flashed
   over WiFi onto the IR node's board), then - Enoch's suggestion - the
   MCP23008 expander was dropped entirely: direction and cliff pins went
   direct. Pins re-mapped twice for his layout. Battery sense
   recalibrated; motor channels and polarity fixed in config after a
   lifted test.
7. **Left-motor trim.** A slight drift was real; a `Left trim` number,
   calibrated on fishcam (0 -> 7 deg/pulse left, +10 -> 5 right, +6 ->
   straight).
8. **Cliff sensors (TCRT5000).** Mounts went through four versions with
   Enoch's fit checks: v1/v2 ribs didn't hold the board, v3 did (Claude
   rendered a three-view drawing for him to validate before printing),
   then Enoch pointed out the sensors sat inboard of the wheels - v4 puts
   each sensor on its tyre's centreline 65 mm ahead of the axle, PCB
   turned across the robot, slimmed to a spine + arm after his review.
   Powered at 3.3 V (DO is pulled to VCC; 5 V would exceed the ESP32).
9. **The Eufy's IR, the long fight.** Captures of the remote decoded into
   a frame `68 CMD HH MM 5C SUM` - **the remote stamps the current time
   into every command**, which is why last week's recorded codes were
   ignored. Transmitting failed for days: a mis-wired receiver, a 100 ohm
   resistor in the wrong place, a board "GND" at 3.3 V, receiver
   saturation, an ESP8266 software carrier the receivers never decoded -
   and, finally, **Claude's own bug**: the ESP32 receiver had been given
   all 512 RMT symbols, so the transmitter silently failed to initialise
   and every "send" since 10/02 emitted nothing. Enoch's meter (0 V on
   the pin) found it. With the RMT split, a hardware carrier, an NPN
   driver (~105 mA) and time-stamped frames: **Forward and Home worked,
   from 2 m.**
10. **blackcam - the Eufy's lid board.** A spare T-Camera now does camera
   and IR (LED driver on IO22; the OLED dropped so IO21 never moves and
   the I2C bus stays quiet). It drove the Eufy off its dock and back.
11. **Grover through the house (10/04).** Hardwood and rugs, short
   checked legs with a camera frame per pulse. Early on it met a wall at
   an angle - the TFMini went from "far" to "too close to measure" and
   neither the firmware nor Claude's loop treated that as an obstacle;
   both were fixed on the spot. Later it passed Taters on her bed,
   stopped for a dog that sat up in a doorway, and finished at the
   kitchen threshold because two people were standing ~1.5 m ahead (a
   rover at people's feet is a trip hazard).
12. **Today (10/05).** Temporary IR rig removed from rover32. A guard
   test was spoiled by another sudden swing, then by forward refusals at
   62-90 cm; logging the guard flags showed `battery_ok=0`: the port's
   battery filter published once per 2.5 min and latched "low" from a
   bad sample after every reboot. Rewritten (rolling 5 s, boot grace,
   re-arm on any reading > 9.6 V). Added a 100 ms full-power kick start
   so both wheels break stiction together - the leading suspect for the
   swings, since mechanics and wiring checked out.

### Decisions, 09-29 .. 10-05
| Decision | Who | Why |
|---|---|---|
| Trike instead of tank | Enoch raised it; Claude chose | track skid caused stiction and asymmetry |
| Brake-on-stop switchable, boots off | Claude | A/B showed no benefit on short pulses |
| TFMini direct (no Qwiic boost chain) | Enoch spotted it; Claude planned | removes three parts from the power path |
| Move the spinal cord to an ESP32 | Claude | a wedged I2C sensor must never freeze the motors |
| Drop the MCP23008 entirely | Enoch suggested; Claude agreed | no I2C left in the motor path |
| Cliff sensors at 3.3 V, DO to GPIO35/32 | Claude (correcting its own 5 V note) | ESP32 inputs are 3.3 V |
| Cliff mount v4 geometry (tyre centreline, 65 mm lead) | Enoch found the gap; Claude designed; Enoch trimmed it | angled approaches could put a wheel over first |
| Grover = bench platform; Eufy = Phases 2-3 | Claude | the Eufy already docks, charges, bumps; Grover is cheap to crash |
| Eufy IR on blackcam (camera + IR on one T-Camera, IO22) | Enoch offered the board; Claude chose the pin | one lid board, quiet I2C bus |
| Use the ESP32 hardware carrier, not the ESP8266 | Claude, from the evidence | software carrier never decoded |
| Stop rules for driving in the house (frame per pulse; stop on close range, invalid-after-close, weak WiFi; never toward people/animals) | Claude | the wall bump |
| Guard treats "close, then invalid" as an obstacle | Claude | the wall bump |
| Battery guard rewrite; kick start | Claude | latched-low guard; stiction asymmetry |
| Prints: drawings for validation before printing | Enoch's request, Claude adopted | caught two design errors before they cost a print |

### Lessons (for the next model, or a human)
- **Read the boot log for FAILED components before debugging hardware.**
  A day of IR testing went into a transmitter that never initialised.
- Instrument before guessing: logging the guard flags found the battery
  latch in one pulse; the idle drain log settled the battery question.
- Narrow-beam LiDAR misses anything off-centre and dark furniture returns
  weak; the camera check per pulse is not optional.
- A photo or a drawing before printing beats a reprint.

### Code and design this week (all in this repo unless noted)
- `brain/` (Python, ~640 lines): MCP server (`status`, `snapshot` for
  three cameras, `drive`, `find_marker`, `home_to_marker`, `set_brake`,
  `set_obstacle_stop`, `stop`), ESPHome API client, ArUco detection with
  per-camera calibration and CLAHE retry, the homing loop.
- Firmware (ESPHome; reference copies in `firmware/`, live configs in a
  private repo): `rover32.yaml` (spinal cord), `blackcam.yaml` (Eufy lid:
  camera + IR), `eufy-ir.yaml` / `eufy-ir8266` / `eufy-ir-c3` (IR test
  nodes), the retired `rover.yaml` (D1 Mini).
- Hardware (parametric OpenSCAD, printed through print-warden):
  `camera-mount`, `camera-strip`, `tfmini-bracket`, `cliff-mount` (v1-v4),
  plus drawings `cliff-mount-drawing.png`, `cliff-mount-v4-drawing.png`,
  `blackcam-ir-wiring.png`.
- ~80 commits this week, 121 in total.

### Open
1. Verify the battery-guard fix and the kick start on the bench, then the
   TFMini guard test against a box, then the cliff edge-stop with v4.
2. Eufy: lid mounting and power for blackcam; battery/charging telemetry
   (roadmap 2E.6); the brain learning to drive it.
3. Brain as a hosted service (roadmap 3.4c). BMS install (deferred).

---

## 2026-09-28 - Session 2: tooling, camera mount design, pipeline checks

**Model:** Claude Fable 5.1 (`claude-fable-5-1`) - third model on the
project, picked up from the docs plus the running conversation.

### Guidance from Enoch this session
- Proceed independently on the authorized work (camera firmware, mount design)
  and *define the next goal* after workbench mastery.
- The T-Camera (`redcam`) may be reflashed without asking - that device only.
- Print preferences: tree supports when needed, no brim.
- He can run sudo installs on the dev VM if asked.
- Signing off for the night; keep working within the rules but watch his
  Claude token budget (Fable has a limit; fallback is Opus 5.5 or waiting).

### What happened
- **Imagery confirmed:** pulled a 1280x1024 frame from the T-Camera's snapshot
  server (port 8081) - the board currently looks across a desk, tilted.
- **Research, sourced:** the Makeblock plate is an 8mm M4 grid in 2mm
  aluminum (Core Electronics / Studica listings). LilyGO's repo has the V1.7
  schematic and an official ESPHome config *without* mirror/flip - so the
  flips in the current config are from today's mounting, to be reset once
  it's upright on the rover. No 3D model or dimension drawing exists for the
  V1.7 anywhere found, hence the caliper request.
- **Firmware pipeline:** compiled the existing camera config on the current
  toolchain (esp-idf, clean apart from expected strapping-pin warnings) and
  OTA-flashed it; the camera came back serving frames. No config changes yet
  - orientation flags wait for mounting.
- **Printer found:** the Sidewinder X4 Plus is Klipper on an MKS Pi, reachable
  through Moonraker (read endpoints need no key); 300x300 bed, 0.4 nozzle.
- **Toolchain, no root:** OpenSCAD 2021.01 and OrcaSlicer 2.4.2 installed as
  extracted AppImages under `~/.local` via `scripts/install-tools.sh`
  (wrapper scripts, not symlinks - AppRun breaks otherwise). Orca has a
  built-in "Artillery Sidewinder X4 Plus 0.4 nozzle" profile and Generic
  PETG. It still needs GTK/WebKitGTK host libraries - bundling them
  user-side would mean ~300 packages, so the script documents one sudo
  `apt-get` line instead; Enoch offered to run it.
- **Mount designed:** `hardware/camera-mount.scad`, a parametric cradle with
  side rails, open front, USB window, 10° down-tilt, M4 slots on the 8mm
  grid. Rendered to STL and checked visually (matplotlib, since headless
  OpenSCAD can't make PNGs here): the first render leaned the wrong way
  (lens looking up) - fixed by rotating past vertical instead of short of
  it. Dimensions are placeholders pending measurement.

### Decisions
**Claude-driven:** the visual-homing goal proposal; OrcaSlicer over
PrusaSlicer (built-in X4 Plus profile; PrusaSlicer 2.9.6 has no Linux
build); the cradle-with-rails mount design and 10° tilt; flashing the
rebuilt firmware as a pipeline check.

**Enoch-decided:** the flash permission scope, print preferences, offering
sudo, and the token-budget constraint.

### Later the same night (Enoch briefly back)
- He ran the apt line - after a fix: `libgtk-3-0` is `libgtk-3-0t64` on this
  Ubuntu, and one unknown name makes apt-get abort the whole install.
  Orca then started headless.
- New constraint from Enoch: **the micro-USB (and 5-pin connector) are on the
  board's bottom edge.** Redesigned the cradle: it now floats on a pedestal
  with an open gap under the board for the plug and a rear cable window,
  resting on two corner tabs instead of a solid end-stop.
- Slicing pipeline built and proven: Orca's CLI rejects presets that
  `inherits` (duplicate-config error), so `scripts/orca_flatten_preset.py`
  flattens the X4 Plus machine / 0.20mm Standard process / Generic PETG
  filament chains into standalone JSON, with the house rules
  (`hardware/slicing/house-rules.json`: no brim, tree supports on auto)
  applied last. `hardware/slicing/slice.sh` does it in one command and
  extracts the G-code from the 3MF. Placeholder-dimension slice: **1h 14m,
  17.2 g PETG**, a few tree supports under the 10° lean. Files committed
  under `hardware/prints/` and uploaded to the printer's `rover/` folder
  (not started) at Enoch's request, labelled PLACEHOLDER-DIMS.
- Enoch asked about the brain and an MCP server. Recommendation given (not
  yet approved): both ESP boards stay ESPHome (spinal cord + eyes); the
  brain is an off-board Python service (OpenCV marker detection +
  aioesphomeapi driving) fronted by an MCP server with `snapshot`, `status`,
  bounded `drive`, later `home_to_marker` - the same shape as the boat's
  shore server. Firmware guards remain the authoritative safety layer.
- Confirmed for Enoch: the mount leans forward, camera 10° down (`tilt`).
- **Brain approved and built** (`brain/`): an MCP server (official MCP Python
  SDK, pinned to 1.x - 2.x renamed the server class the same week) with
  `status`, `snapshot(bench|rover)`, a hard-capped `drive` (<=1.0 s, 0.3 s
  gap, refused under 9.6 V or with a cliff active except backward), and
  `stop`. Hosts/keys come from `~/.rover-brain.env` via `brain/run.sh`, never
  the repo. Tested through a real MCP stdio client: tools list, both cameras
  return JPEGs; `status` correctly errors with the rover powered off.
  Registered with Claude Code at user scope as `rover-brain`.
- Board consolidation, discussed: Enoch asked whether the T-Camera replaces
  the D1 Mini. First answer was no (its GPIOs are all taken by the camera
  bus/OLED/PIR); Enoch pointed out the I2C expanders on hand (MCP23008, and
  16-pin MCP23017s), which makes it *possible* - direction pins via an
  expander, the two PWM lines via a PCA9685 (or PCA9685 alone). He also
  noted two boards drain the pack faster: ~0.9 W for the D1 Mini (half of
  it the L298N's linear regulator) vs ~1.5 W for the streaming camera -
  roughly 12 h idle with both, ~18 h with one, on a ~28 Wh pack. Decision:
  keep two boards through visual homing (the safety firmware is tested and
  the bench phase is about not falling off), then consolidate. Cheap wins
  first: feed the D1 Mini from the buck, sleep the camera when idle.

- Enoch signed off; measurements coming in the morning. Asked for a roadmap
  of future tasks/capabilities - written as `ROADMAP.md`. Also generated
  the printable homing marker and the brain's marker detector as groundwork
  (see the roadmap and `brain/markers.py`).

- **Issue #1 (Enoch): an old Roomba with the Open Interface port as a
  chassis.** Researched the OI spec and the open-source ESPHome components
  for it. Decision (Claude-driven, posted on the issue): adopt it as the
  house chassis and the path into Phase 2 - docking/charging, cliff x4,
  bump, encoders and battery telemetry come built in, retiring the dock/
  charger/BMS build - conditional on model and battery health; keep the
  Makeblock rover for the bench. Roadmap gained Tier 2R; BOM a candidate
  section. Waiting on Enoch for model number, health, and a mini-DIN plug.

- Test-fit print of the mini-DIN plug run overnight at Enoch's request (he
  authorized this one print), monitored through the printer camera with the
  workbench light switched on only for each shot: completed in 18 min,
  0.76 m of PETG, clean. The part is on the printer bed for him to test-fit
  in the Roomba's port.

- Morning news from Enoch: the plug test print's fit was off (key should be an
  inset groove, wire holes too small - both fixed in the file and shelved),
  and moot anyway - the Roomba had been given away. He has a **Eufy RoboVac
  12** instead. Researched it: the 11/11S/12 family is IR-remote controlled
  and ESPHome already drives them with Pronto codes; a deeper published hack
  reads battery/charging inside the shell. Decision (Claude-driven): the
  Eufy becomes the house chassis over IR, keeping its own docking/charging/
  cliff/bumper behaviour; roadmap Tier 2R rewritten as 2E. He also said the
  design-print-monitor loop working autonomously was "pretty spectacular".

- Enoch: the Eufy runs and dock-charges, the remote's on hand, IR
  receivers/LEDs in inventory, spare ESP32 devkits available. Verified via
  Eufy's own remote listing (one T2108 remote for 11S/12/15T/30) that the
  published 11S IR codes are the 12's. Built `eufy-ir.yaml`: an ESP32
  devkit IR bridge - transmitter on GPIO4 with the 11 remote functions as
  buttons, receiver on GPIO14 in dump mode as the fallback. Validates and
  compiles; needs one USB flash (HA's ESPHome dashboard), OTA after.

- IR node flashed by Enoch (ESP32-WROOM-32D devkit, factory image sent to
  him directly) and online. Captured his remote with the node's receiver:
  six clean codes (forward/back/left/right/home/start-stop). Finding: the
  RoboVac 12's remote shares the 11S protocol and 9-bit address prefix but
  its command payloads differ - the published 11S codes would not have
  worked, despite Eufy listing one remote for both. Rebuilt the node with
  the captured codes and OTA'd it (Enoch OK'd; recorded in CLAUDE.md).
  Vacuum-response test pending - the Eufy is also refusing to charge on its
  dock, which may mean a dead pack (~$20-30 if so).
- Camera mount: Enoch measured the board (28.0 x 68.0 x 1.27 mm, 6 mm rear
  components, USB centred) and clarified the USB lead runs straight down in
  line with the board, not bent backward. v3 adds a cable slot through the
  base aligned with a Makeblock plate hole. Sliced (1h 18m, 18 g), on the
  printer, awaiting his go.

- Camera mount v3 printed on Enoch's go: 80 min, 5.9 m of PETG, monitored
  at 4/31/57/86 % through the printer camera (light on only per shot) -
  clean throughout, tree supports did their job under the lean. Part is on
  the bed for him to de-support, test-fit the T-Camera, and bolt to the
  Makeblock plate.

- Enoch's photos of the v3 print with the board in it exposed a third
  problem beyond the two he named: full-length front lips can't work on
  this board (buttons at the edges, OLED nearly full-width). v4 fixed the
  outward-offset tabs/lips; v5 replaced the lips with 4.5 mm corner lips
  (upper ones chamfered for tilt-in). He judged v5 workable; printing.
- Power: the USB lead is soldered to the buck but there's only one, so it
  can't feed both boards. Recommendation given: feed the D1 Mini from the
  buck too (and disconnect it from the L298N's regulator - never parallel
  two regulators), via breadboard rails for the bench phase or a second
  soldered lead for anything that moves. Enoch's choice pending.
- The Eufy's pack is dead (dock lights up, vacuum never runs). Researched:
  14.4 V 2600 mAh replacements run ~$17 (eBay) to ~$20-25 (Amazon/Walmart).
  Proposed on the BOM shopping list against Claude's budget; awaiting OK.

- Plot twist: the Eufy's pack isn't dead - its bottom power switch was off.
  Enoch cancelled the battery order; the ledger is back to $0 spent. The IR
  drive test can happen as soon as it's charged.

- Camera mount v5 printed: 82 min, 6.6 m of PETG, clean at every check
  (6/38/69 %). On the bed for Enoch to de-support and test-fit - the corner
  lips and inside tabs are the things to verify this time.

- Eufy IR test, first live attempt: with the vacuum on the workbench and the
  node on its lid, Forward presses did nothing; the node's own receiver
  heard the LED (fragments only - receiver saturation at 2 cm, so loopback
  proves emission, not fidelity). Raised RMT buffers to 256 and set 3x
  repeats per press. Then, after Enoch repositioned node and vacuum, it
  **started reversing toward the bench edge** and he caught it. No job of
  mine was sending at the time. Unexplained; suspects are a label shift in
  the captured codes or the vacuum's own start-up behaviour. New rule in
  CLAUDE.md: the Eufy is tested on the floor only.

- Marker printed and placed on the bench; `find_marker` found id 0 live on
  the bench camera (48.6 px wide, dead centre) - first real detection.
- Rover powered on: brain `status` works (10.58 V idle, cliffs quiet), and a
  0.3 s backward pulse through the brain's client drove and stopped cleanly.
  Battery read 9.82 V right after the pulse - sagging near the brain's
  9.6 V refusal line; the pack needs a charge soon.
- T-Camera would **not** power from 5 V/GND on its bottom 5-pin connector;
  micro-USB is the only usable input. It's temporarily hanging from the
  pegboard on wall USB, looking down at the bench; its view is rotated by
  that mounting, so orientation flags wait for the bracket.
- The spliced USB lead delivers nothing at the plug despite ~5 V at the
  buck - diagnosis steps given (wire identification by continuity, broken
  conductor at the strain relief, polarity).

- Eufy on the floor: Home then Forward from the node did nothing. Loopback
  on the node's own receiver isn't proof of emission (38 kHz GPIO noise can
  couple in), and Enoch's phone saw no flicker (940 nm is nearly invisible
  to phones). Tried to see the LED with the bench camera: daylight mode
  blocks IR; forced night mode via Thingino's `json-imp.cgi` (cmd=daynight
  val=night|day; ir850/ir940 floods toggle likewise) - still nothing, but
  the open garage door floods the scene with daylight IR, so inconclusive.
  Next: electrical checks (multimeter across the LED during an 8 s test
  burst; wiring GPIO4 -> 100R -> anode), then a transistor driver if the
  LED is merely too dim.

- **Root cause found for the Eufy IR failure: the IR LEDs.** Two IR LEDs
  (swapped in turn) never showed on the night-mode bench camera; a visible
  LED in the same spot lit brightly on the 8 s test burst, so the node,
  IO4, the RMT transmitter and the captured codes are all fine. Possible
  mix-up with look-alike IR phototransistors (dark = receiver, clear =
  emitter). Enoch has new IR LEDs on order (his own purchase). The
  test-burst button stays in the firmware for the 30-second verification
  when they arrive; a transistor driver is the next step only if the
  vacuum ignores a working LED at distance.

- Bench camera calibrated for distance: Enoch measured lens-to-marker at
  66 in; the marker spans 50.7 px there, so the focal length is 1062 px
  (~84 deg horizontal FOV). The brain now holds a per-camera focal length
  (`BENCH_CAM_FOCAL_PX`, `ROVER_CAM_FOCAL_PX`) and `find_marker` reports
  distance - verified: 1676 mm back at 66 in.

- T-Camera mounted in the bracket on the rover and powered ("janky, but
  connected"). Its view is upright and un-mirrored as mounted, so the
  existing flip settings are right - no firmware change. The marker didn't
  decode at 50.75 in (too small: this lens is a fisheye), so Enoch moved it
  to 24 in: 57.3 px there -> ROVER_CAM_FOCAL_PX = 437 (~111 deg FOV).
  Verified 610 mm back at 24 in, bearing +10.2 deg. Generated a 160 mm
  id-1 marker page for longer range.

- **MILESTONE: visual homing works.** Wrote `brain/homing.py` - a closed
  loop (look, pivot toward the marker, step forward, settle, look again)
  with hard caps, lost-marker abort, and battery/cliff checks before every
  pulse - exposed as the `home_to_marker` MCP tool. First run stalled: a
  0.2 s pivot is below stiction on the bench (12 pulses, 1.3 deg total).
  Added adaptive pivot pulses (grow 1.5x when a pulse has no effect) and a
  6 deg centre tolerance. **Second run arrived: 12 pulses, from 594 mm and
  +4.9 deg to 90 mm and -4.4 deg, unattended.** The last 0.3 s step
  overshot the 200 mm stop, so steps inside 350 mm are now 0.15 s.
- Enoch found a Benewake TFMini micro-LiDAR with a Qwiic (I2C) adapter and
  breakout in inventory - added to the roadmap as the forward range sensor
  (better than the HC-SR04 for a precise stop distance and obstacle stop).

- Bench camera swap (handoff from the homelab-helper session, note in
  `handoffs/`, LAN addresses stripped on arrival): **agreed by Enoch,
  deferred until bench testing is done.** camv3 -> the PTZ "fishcam";
  camv3 goes to the printer. Rover side: new BENCH_CAM_HOST + password,
  one-time bench-cam recalibration, two PTZ presets ("bench", "wide").
  Future prints go through the print-warden MCP, which reuses this repo's
  slicing rules.
- **Homing against the 160 mm marker (id 1), later the same night** - a
  string of fixes from real runs:
  - Every other pulse looked ineffective because the camera's snapshot
    endpoint was serving frames up to 10 s old (`idle_framerate` was
    0.1 fps). Set it to 5 fps (needs `psram:`), reflashed, and `_look`
    now discards one frame and uses a second.
  - The loop ground against a mat edge/cables at 229 mm - added a stuck
    guard (three pulses with <0.5 deg / <15 mm change -> stop). A single
    1.0 s `backward` pulse freed it. Enoch then cleared the lane.
  - Still "stuck" at 325 mm with a clear lane: **left pivots do nothing
    at 0.2-0.6 s while right pivots bite at 0.25 s**; one 1.0 s left pulse
    turned it 12 deg (Enoch watched the left track move), then three more
    1.0 s left pulses did nothing at all. Loop changes first: pivot pulses
    adapt per direction, the cap is now 1.0 s (the server's max), and a
    no-effect pivot doesn't count toward "stuck" until its pulse has grown
    to the cap.
  - **Root cause: torque margin, not wiring.** Firmware drives both sides
    at the same duty, and with the rover lifted (Enoch's eyes) both tracks
    ran in sync forward and back. Under load, a tank pivot scrubs both
    tracks sideways and 75% duty was right at the edge - one direction
    got over it, the other didn't. With Enoch's OK, `left`/`right` now run
    at **100% duty** (forward/backward stay 75%). Result: 0.3 s pivots turn
    ~24 deg in *either* direction; initial pivot pulse dropped to 0.1 s.
  - **Second autonomous arrival, first on the 160 mm marker:** 667 mm ->
    214 mm in 14 pulses. The previous run had actually parked at 173 mm
    and 4.5 deg but reported "marker lost" - close in, the big marker
    overfills the T-Camera's frame and its border gets cropped. Arrival is
    now judged by lateral offset (<=30 mm) as well as bearing, and losing
    the marker right after a pulse inside 1.25x the stop distance counts
    as arrived.
  - **Chassis decision.** Enoch pointed out (not steering, just informing)
    that the Starter Robot Kit also builds as a two-motor trike with a
    trailing caster, and that it came with a Me Orion (Arduino + RJ25)
    board. Claude's call, Enoch proceeding: **rebuild as the trike** - the
    tank had to skid its tracks sideways to pivot, which is where all of
    tonight's stiction/asymmetry came from; wheels on an axle pivot at low
    duty with angle roughly proportional to pulse length, which is what
    homing wants. Same differential steering, so firmware and brain are
    unchanged; only pulse constants get re-tuned. **Keep the D1 Mini +
    ESPHome, skip the Orion** - it has no WiFi so the ESP stays in the loop
    anyway, and the tested watchdog/disconnect/cliff/battery firmware would
    have to be rewritten for no gain.
  - **Camera adapter strip** (`hardware/camera-strip.scad`) designed from
    Enoch's measurements: the two front M4 standoffs are 30 mm tall and
    measure 68.5 mm across the outer edges of their holes = 64 mm c-c (8
    grid units); slots cover 63-66 and are oversized per his request. The
    strip presents the v5 cradle's own M4 slot pair on top. Sliced (21 min,
    8.8 g). Enoch: "once you have designed it, if you're confident, you can
    print" - **printed 2026-09-29.** Fit check after the trike rebuild.
  - Enoch flagged that the bracket sits loosely and shifts on every jerky
    move, which corrupts bearings; he offered to measure the chassis
    posts so an adapter plate can bolt the mount down. Accepted -
    measurements requested (post spacing both axes, post type/diameter,
    height, which way is forward).

### The trike, same night (2026-09-29, late)

- Enoch rebuilt the chassis as the trike in about an hour (drive wheels in
  front, caster at the rear) and fitted the freshly printed camera strip -
  "worked great". Zip-tied the motor leads at his own suggestion.
- **Forward and backward came up inverted** on the new build (pivots were
  correct): rotating the motor mounts swaps sides *and* polarity. Caught it
  on the bench camera after one 0.1 s pulse moved the rover toward the near
  edge; no more pulses until fixed. Fix, with Enoch's OK: the four MCP23008
  motor pins and the two PWM pins are remapped in firmware.
- **Motor duty is now two live sliders** on the rover (`Drive duty` 75%,
  `Pivot duty` 50%), so tuning no longer needs a reflash. Needed at once:
  on the trike a 0.1 s pivot at 100% was ~30 deg. At 50%, 0.05 s is ~3 deg,
  0.1 s ~6 deg, left/right symmetric.
- **Third autonomous arrival, first on the trike: 1109 mm -> 168 mm in 7
  pulses, 35 s, final bearing -0.8 deg.** Four consecutive forward pulses
  held within 2 deg of centre. Near-range step cut to 0.1 s (the 0.15 s step
  overshot the 200 mm stop).
- redcam turned out to still be on ESPHome 2024.9.2: its config has never
  validated on 2026.x (`idle_framerate` max 1 fps; the camera's SCCB pins
  must be a separate `i2c:` bus; the OLED lambda used the Arduino `WiFi`
  object; `IPAddress::str()` removed in 2026.8). All fixed and **both
  firmwares are pre-built** (Enoch's suggestion: build while the pack is
  off, flash the moment it's back) - the rover's with brake-on-stop, the
  camera's on 2026.8.1. `_look` now retries
  transient camera errors and waits 1.2 s between its two frames.
- **Both flashed** once Enoch reinstalled the batteries: two OTA uploads,
  both OK; logs confirm 2026.8.1 with the pre-built compile stamps, the rover
  came back Stopped at 11.8 V and redcam serves frames on the new build.
- **Brake test aborted, camera lost.** First braked stop (0.3 s forward
  pulse, lane checked on the bench cam, marker 1082 mm at +19 deg) went fine
  mechanically - the caster flipped back to trailing and squared the rover
  up - but redcam dropped off WiFi within about a minute of it and had not
  returned 5 min later (no ping; HA unavailable from 09:24). The D1 Mini
  did not reset. Suspects: the brake's current transient disturbing the
  camera's supply, or the new 2026.8.1 camera build being fragile; homing
  runs on the old build survived dozens of unbraked stops. Needs a power
  cycle by hand; test paused until then.
- **Enoch power-cycled redcam** and widened the standing permission: the
  spinal cord, redcam, camv3 and fishcam are all Claude's to flash/modify
  for now. fishcam moved to the far side of the bench (head-on view).
- **Brake A/B.** Added a `Brake on stop` switch (default on; the script
  also now sets the pins to brake *before* EN goes to 100%, so there's no
  full-duty instant in the old direction) and flashed it. The brain got a
  `front` camera, a `set_brake` tool, and a CLAHE retry in marker detection
  - head-on at ~1 m the backlit marker's border merged into dark clutter
  and plain detection failed. Four 0.25 s forward pulses at 75% duty,
  marker distance as the ruler (median of 3 frames, ~+-6 mm):

  | Pulse | Brake | Travel |
  |---|---|---|
  | 1 | off | 128 mm |
  | 2 | on | 152 mm |
  | 3 | off | 153 mm |
  | 4 | on | 141 mm |

  Off averages 140 mm, on 146: pulse-to-pulse spread swamps any braking
  effect, so these gearmotors coast little at this speed (the "~8 cm
  coast" in the firmware comment was never measured). Camera trouble
  after 2 of 3 braked stops (the hang, then one HTTP 500 that cleared on
  retry) and 0 of 2 coasting ones - too few to call, but with no benefit
  shown the brake is left **off**. Retest at cruise when there's room.
  Rover left at 448 mm from the marker.
- **Pack draining fast at idle:** 11.7 V at ~09:20 -> 9.67 V at 09:45,
  falling ~0.07 V/min while Stopped (cameras + boards only). Far too fast
  for idle load - suspect a weak cell or a pack not fully charged. Asked
  Enoch to power off and charge, and to read per-cell voltages first if
  handy.
- **Enoch swapped in a different pack** (he has several). 30-min idle
  log: 11.84 -> 11.62 V, ~0.007 V/min and flattening - ten times slower
  than the old pack, so the old cells were the fault (11.7 V is only
  ~70% charge; the drain implied ~0.2 Ah usable). Neither pack went in
  at full charge (4.2 V/cell = 12.6 V).
- The brake switch came back **on** after the pack swap: ESP8266 switch
  state isn't persisted, so it fell to its RESTORE_DEFAULT_ON. Firmware
  now boots it off (`ALWAYS_OFF`), flashed and confirmed.
- Battery options discussed with Enoch (asked what's in inventory before
  pricing anything): a 3S BMS on matched 18650s (per-cell protection the
  pack-level 9.3 V guard can't give), an INA219 for current, matched cells
  charged full. Skipped for Grover: RC LiPo, USB-C PD bank + trigger,
  LiFePO4 - the Eufy carries the recharging mission.
- **Enoch ordered a 3-pack of 3S 40A BMS boards** ($8.66) for inventory;
  Claude took one for Grover, first budget draw ($2.89, $97.11 left).
  Wiring plan in BOM; soldering balance taps onto the holder to be
  discussed with Enoch when it arrives.
- **Enoch handed over milestone choice** ("you tell me what you want to do
  next") - recorded in CLAUDE.md. Claude picked the TFMini (roadmap 3.4).
- **TFMini, software side done before the hardware.** SparkFun's guide:
  the Qwiic TFMini's own cable carries 5 V directly (red 5V, black GND,
  white SDA, green SCL), so it runs off the buck and skips the adapter's
  3.3->5 V boost (the D1 Mini's regulator can't feed its ~800 mA peak);
  it reports invalid under 30 cm. Firmware: read at 10 Hz on the existing
  I2C bus (MCP23008 at 0x20, TFMini 0x10), `Front range` / strength /
  valid sensors, and an `Obstacle stop` guard (cm, 0 = off, boots off
  until verified) that refuses forward and stops a forward move inside the
  threshold. The guard holds through invalid frames (an object that got
  under 30 cm must not clear it) and, when enabled, treats a missing
  sensor as an obstacle. Flashed with no sensor attached: clean boot, no
  log spam, forward unaffected. Brain: range fields in `status`,
  `set_obstacle_stop(cm)` tool.
- Mount: the front blue beam above the motors (~5 cm off the bench) looks
  right from the fishcam view - low enough for small obstacles, and level
  keeps the 2.3 deg beam off the bench for a couple of metres. Needs the
  beam's hole layout and the sensor's mounting details from Enoch.
- **Power plan agreed with Enoch's inventory:** today the D1 Mini runs off
  the L298N's 5 V (linear) regulator and the camera off the buck. New: the
  D1 moves onto the buck's 5 V, and the TFMini's Qwiic 3.3 V line gets its
  own LD33V off that same 5 V (Enoch ran the TFMini this way before) - the
  SparkFun Qwiic Adapter is pass-through, the 3.3->5 V boost lives on the
  TFMini's cable board, so the D1's ~500 mA regulator would otherwise carry
  it. Enoch is doing the rework. He noted the LD33V build never had its
  10 uF caps - add them (LD1117 needs >= 10 uF on the output); the LD33V
  pinout is GND-OUT-IN, not a 7805's.
- Fishcam's PTZ works through HA's `onvif.ptz` (ContinuousMove; RelativeMove
  returns 500) - tilted down to inspect the parts on the bench, then back.
- **TFMini bracket designed** (`hardware/tfmini-bracket.scad`): ear holes
  from Benewake's TFmini-S drawing (Enoch's link; 2 x 2.35 mm at 36 mm
  c-c, same housing). Enoch: the beam's top face is free (the clear plate
  is set back), holes are top/bottom on the standard grid, not threaded,
  and the centre pair is taken by the bracket under the beam that joins
  the caster beam - so the part bolts through the next holes out (+/-12)
  with a relief pocket over the centre pair, and hangs the sensor in front
  of the beam at its mid-height. Staged via print-warden (job 010780c633,
  29 min, 7.9 g PETG); Enoch: "OK, print it" - started. Grover drove ~15 cm
  toward fishcam for a look at the beam and veered right (toward the long
  edge, ~13 cm clear); left there.
- **TFMini goes direct.** Enoch spotted the as-built chain was 5 V ->
  LD33V -> 3.3 V -> boost board -> 5 V. The TFMini takes 5 V and talks
  3.3 V I2C, so it can run straight off the buck with SDA/SCL on the D1
  Mini. He'd rather not cut the stock cable, so he ordered a GH1.25 ->
  Dupont 2.54 pre-crimped kit (Amazon B087N4GY8Z) for inventory; Grover's
  prorated share is $0.40 (budget: $3.29 spent, $96.71 left). The Qwiic
  chain + LD33V remains a stopgap until the kit arrives. Bracket printed
  meanwhile (print-warden: done, 36 min).

## 2026-10-01 .. 10-03 - TFMini bring-up, IR node debugging, BMS arrives

**Model:** Claude Fable 5.1. Enoch at the bench throughout, doing the
wiring; Claude flashing and reading logs. Auto mode was switched off
mid-way (Claude had flashed the IR node while Enoch was repositioning it,
which rolled the OTA back); rover, cameras and IR node stay Claude's to
flash, but Claude now says what it's about to do to a device Enoch has
in his hands.

### TFMini (done - reading)
- First attempts: with the TFMini's I2C wires on, the D1 Mini crawled
  (API handshake 5 s, status reads timing out) and the boot scan reported
  "SCL is held low" - no devices at all, MCP23008 included. First cause:
  the TFMini chain was unpowered (pack out, LD33V fed from the buck), an
  unpowered device clamps the bus. Then with the kit lead (direct 5 V,
  no Qwiic adapter) the scan found 0x10 and 0x20, but every transaction
  took 3 s: write NACKed, read timed out, and the sensor was left holding
  SCL low until a power cycle.
- Diagnosis by instrumenting the read (1 s poll, timing + raw bytes).
  Fix needed all three: **repeated-start** write/read (`write_readv`, as
  in SparkFun's example - a stop between command and read is refused),
  **100 kHz** (bus was 50), and an i2c `timeout: 20ms` (clock-stretch
  limit; the ESP8266 default is 230 us). Each try needed Enoch to
  power-cycle the rover because an OTA reboot doesn't reset the sensor.
- Result: reads in ~2 ms, valid frames, 77 cm at strength ~434 on the
  bench. Back to 10 Hz. The sensor was already in the printed bracket
  (fits; centred, level). **Calibration: 78 cm by TFMini vs 77 cm by
  tape to the marker** - within spec, no correction.
- **Guard verified:** set 35 cm, pulsed forward; at 30 cm the firmware
  logged "Forward blocked" and the motors stayed off. Guard now boots at
  35; `home_to_marker` relaxes it to 0 once the camera has the marker
  inside 35 cm (camera owns the last stretch) and restores it on exit,
  and reports "obstacle ahead at N cm" instead of grinding on a refusal.
- The ~90 deg left swing over three "forward" pulses was **not** the
  motors: both ran fine lifted (10 s test), and a repeat on the bench
  showed two straight pulses then a swing when, as Enoch saw, a wheel
  clipped an obstruction on the bench. The TFMini can't see low or
  off-axis objects (2.3 deg beam at ~5 cm height) - the lane check on the
  cameras stays mandatory.
- ...but a slight real drift remained (Enoch), and a later run swung
  hard left at the start of a pulse. Added a **Left trim** number
  (scales the left motor's duty on forward/backward) and calibrated it
  on fishcam: 0 -> ~7 deg/pulse left, +10 -> ~5 deg/pulse right, **+6
  -> straight** over three pulses; now the firmware default. Mechanical
  suspects for the hard swings (left wheel set screw, caster sitting
  sideways at pulse start) still worth a look.
- redcam came back on a new DHCP address; `~/.rover-brain.env` updated.
- Enoch: the IR node's ESP32 devkit is to become the new spinal cord
  (3.4d) - IR work stops. **Port done and compiled** (`rover32.yaml`,
  esp-idf): MCP23008 on bus_a (GPIO21/22), TFMini on its own bus_b
  (GPIO25/26, 100 kHz, 20 ms timeout), PWM on GPIO16/17 (ledc), battery
  divider straight into GPIO34 (12 dB attenuation, x4.704 - needs
  calibrating against a meter; the D1 Mini had an extra onboard divider).
  Device name `rover32` so both boards can coexist during the swap. First
  flash by USB from the HA ESPHome dashboard, then OTA. Wiring moves
  listed in README/BOM. Enoch asked whether to keep the MCP23008 now that
  pins aren't scarce: **dropped** - direction on GPIO18/19/23/27, front
  cliff on GPIO35/32, rear cliff reserved on 33/13 (36/39 are only
  labelled VP/VN on this devkit). No I2C left in the motor path at all;
  the TFMini is the only bus device.
- **rover32 brought up** (flashed OTA onto the IR node's board while it
  still ran eufy-ir - no USB needed). TFMini found on bus_b once SDA/SCL
  were the right way round (first "shifted by a pin", then swapped);
  battery sense needed its wire moved, then calibrated x4.664 (12.00 V
  read vs 11.90 V meter). Buck set to 5.198 V. Lifted motor test, then
  on the bench: forward ran backward and left pivoted right = both
  polarities flipped as wired -> fixed in config (swap fwd/rev pins per
  side; the channel ids also crossed to match the wiring). Verified by
  LiDAR range falling on forward and the marker swinging into view on a
  left pivot; Enoch confirmed. Brain now points at `rover32`; the D1 Mini
  is retired. TFMini 0xFFFF (no return) now counts as invalid.
- **Cliff sensors arrived** (HW-870 / TCRT5000, 31.5 x 14 mm, hole 7.5 mm
  from the pin end). Mounts designed (`hardware/cliff-mount.scad`, L
  bracket from the beam's end holes, sensor ~8 mm above the bench on a
  6 mm spacer boss) and printed on Enoch's "print them". Wire DO (not AO)
  to GPIO35/32, VCC 5 V.

## 2026-10-03 .. 10-04 - cliff mounts v3, IR node on the D1 Mini

**Model:** Claude Fable 5.1, then Claude Opus 5.5 from late 10/04 (Fable's
usage limit; the fallback CLAUDE.md names). Enoch at the bench.

- **Cliff mounts:** v1 ribs stopped short of the screw; v2 lengthened them
  along the shelf but they were only boss-high and never touched the
  board's edges (Enoch caught both). v3 ribs drop past the board on both
  sides; Claude rendered a three-view drawing (`hardware/cliff-mount-
  drawing.png`) for Enoch to validate before printing. Right v3 fits well;
  left v3 printed too (Enoch had said to skip it, but it had already
  started - cancelling is his gesture, not Claude's).
- **Battery:** one cell in the current pack is bad (Enoch found it after
  rover32 kept browning out). Swap that cell before the next long session.
- **IR, still unsolved.** The retired D1 Mini is now `eufy-ir8266` (D5
  receiver, D2 LED). Findings:
  - The first receiver was off-band or failing; a VS1838B (38 kHz)
    decodes the remote perfectly - so the remote is 38 kHz.
  - Our transmissions (8266 software carrier, ESP32 hardware carrier via
    rover32 on GPIO4, 36-60 kHz sweeps, 10 and 50 cm, bounce) only ever
    produce short fragments on that receiver - never a frame. A frame
    sent with NO carrier gives the same fragments, which means the
    receiver isn't seeing a 38 kHz-modulated light from our LED.
  - On the 8266, D2 averages 1.43 V and the 100 ohm drops 0.79 V during a
    burst, i.e. the pin toggles and the LED conducts. LEDs are kit
    940 nm clear emitters (Enoch confirmed).
  - A raw pin recorder on rover32 (GPIO33 jumpered to GPIO4) saw nothing
    during an 8 s burst - either the jumper or GPIO4's output; not
    resolved.
  - The remote's frame is `68 cmd XX YY ZZ sum`; the three middle bytes
    change between sessions (00 14, 00 07, 05 1B FF, 03 12 00) - looks
    like the remote's clock. Command bytes are stable.
  - Next: meter GPIO4 during a burst on rover32; swap to another emitter;
    if still fragments, buy a known-good IR transmitter module. rover32
    carries a temporary IR rig (TX GPIO4, raw RX GPIO33) to remove later.
- **IR SOLVED (10/04, 16:00): the Eufy drove forward on our command.**
  Three causes, all found the same afternoon:
  1. **Claude's bug:** on 10/02 the ESP32 receiver went to 512 RMT
     symbols to stop a crash - the chip only has 512 in total, so the
     transmitter failed to initialise ("out of RMT symbol memory",
     component FAILED) and every ESP32 send since logged "send" but put
     nothing on the pin. Enoch's meter on GPIO4 (0 V) found it. Fix: RX
     256 + TX 192. Lesson: read the boot log for FAILED components before
     debugging hardware.
  2. **The ESP8266's software carrier** never produced a decodable frame
     on a VS1838B; the ESP32's hardware (RMT) carrier did at once
     (`68 4F 00 07 FF BD` decoded back exactly). Use the ESP32.
  3. **The frame carries the remote's clock.** Format, confirmed against
     a fresh capture: `68 CMD HH MM 5C SUM`, HH = 12-hour hour, MM =
     minute (both binary), SUM = low byte of the first five. (The "5C"
     byte drifted between sessions too - 00/FF earlier - so treat it as
     "copy the latest capture".) Old captures with stale times were
     ignored. Forward (0x2C) stamped with the current time worked from
     ~3 cm off the bumper with the vacuum off the dock; Start/Stop was
     ambiguous. Command bytes: Fwd 2C, Back 7C, Left 3C, Right 6C, Home
     EF, Start/Stop 4F (+ 5C, 1D, AD, 5D unlabelled).
  - **Home (0xEF) also worked** (16:01) - the vacuum returned to its dock.
    Two commands now confirmed: Forward and Home.
  - Range: a 20 mA LED decoded with bit errors at 50 cm. **NPN driver
    added** (GPIO4 -> 1k -> base, emitter GND, 5 V -> 33 ohm -> LED ->
    collector, ~105 mA): loopback 18/24 frames clean, and **Forward worked
    from ~1 m** (16:16) **and from 2 m** (16:17). Test burst cut to 1 s so the 20 mA-rated LED
    isn't held at ~50 mA average. Next: find the max range, then move the
    IR to its own ESP32 node and strip the temporary rig off rover32.
- **IR's permanent home: blackcam** (Enoch's spare T-Camera V1.7, which
  powers from its bottom header unlike redcam). Flashed as the Eufy's lid
  board: camera + IR on IO22 (OLED dropped; IO21 untouched so no I2C
  START can happen on that bus), SNTP-stamped frames, buttons + an
  `eufy_command` action. Boot log clean (no FAILED). A C3 Super Mini
  config (`eufy-ir-c3`) is kept as a spare IR node.
- **Grover's direction set** (Claude, 2026-10-04): Grover becomes the
  bench test platform for the brain; the Eufy carries Phases 2-3.
- **Cliff sensors installed on Grover**, powered from **3.3 V** (DO is
  pulled up to VCC; 5 V would exceed the ESP32's inputs - corrected from
  the earlier 5 V note). GPIO35 front-left / GPIO32 front-right (wires
  were swapped at first; Enoch fixed). Both read clear on the bench and
  cliff when lifted. Edge-stop drive test next.
- **First floor run (dining room, hardwood).** Cliff sensors read clear on
  hardwood; ~22 cm per 0.3 s pulse, straight with the +6 % trim; TFMini
  tracked 3.9 -> 3.2 m. Then a 12-pulse scripted run toward the window
  ended **nose to a wall corner**: Grover drifted off line, met the wall
  at an angle, and the TFMini went from "far" straight to invalid (<30
  cm) - the firmware guard holds state on invalid readings, so it never
  tripped, and Claude's loop only checked valid readings, ran without a
  camera frame per pulse (weak WiFi, -82 dBm, made it slow) and timed out.
  A light bump at ~22 cm/pulse at most. **Fixes:** firmware now treats
  invalid-after-close (last good < 60 cm) as an obstacle; driving loops
  take a frame per pulse and stop on weak WiFi. One 0.3 s reverse
  (Enoch: safe) backed it to 53 cm. Cliff mounts v4 (sensor on the tyre
  centreline, 65 mm ahead of the axle) printing.
- **House run, continued** (Enoch: "keep going until you'd break one of
  the original rules"; reversing/pivoting allowed - no fall hazard; light
  on; Taters elsewhere). Short legs, a camera frame per pulse, stops on
  close range, invalid-after-close, cliff or weak WiFi. Dining room ->
  past the sideboard -> foyer, ~4-5 m. Findings: the TFMini's 2.3 deg beam
  misses anything off-centre (caught a sideboard leg at 52 cm; pushed
  into an orange object at the front-left corner it never saw); dark
  furniture returns weak/invalid readings; ~1-2 deg/pulse left drift on
  hardwood even with the +6 % trim. Stop rule refined: invalid readings
  stop only when the last good one was < 150 cm. **Stopped at the
  living-room opening:** Taters' position unknown and a lying dog is low
  and soft - the TFMini and a rover-height camera can't clear that, which
  would risk the "never harm an animal" rule. House roaming stays the
  Eufy's job (bumpers); Grover remains the bench platform.
- Enoch: Taters ignores robots (lies on her bed, maybe barks) - so the
  run went on into the living room (hardwood and rugs fine; rug edges
  climbed; cliff sensors read rugs as floor). Stopped by sun glare toward
  the French doors (camera blinded, and sunlight affects the TCRT5000s)
  and parked at the TV stand. Battery 11.3 V after ~10 m of driving.
- **blackcam drove the Eufy.** Enoch wired the NPN driver to its header
  (diagram `hardware/blackcam-ir-wiring.png`) and aimed it from above; a
  single `eufy_command(0x7C)` (Backward, SNTP time-stamped) backed the
  Eufy off its dock, seen through blackcam itself. Lid board proven:
  camera + IR on one T-Camera. (Claude first proposed Forward from a
  flipped camera view - Enoch corrected it; the T-Camera image is
  mirrored/flipped, mind the orientation.)
- blackcam also sent **Home**: the Eufy re-docked (charging light on).
- Grover to the kitchen: Enoch gave the route (slight right, forward,
  left into the doorway). Passed Taters on her bed at >1 m; a dog sitting
  up inside the doorway stopped Claude until Enoch said he was watching;
  ended on the doormat at the kitchen threshold and stopped there - two
  people standing ~1.5 m ahead, and a rover at their feet is a trip
  hazard. Whole run ~12-14 m, dining room -> foyer -> living room ->
  kitchen doorway, battery still 11.3 V.
- Back on the bench: rover32's temporary IR rig removed (IR lives on
  blackcam). **Guard test aborted:** aimed at a cardboard box, Grover
  swung ~90 deg on the second pulse (camv3 + rover cam). That is the
  fourth sudden swing at a pulse start (bench x2, floor x1, now), with
  the wheels mechanically fine and both motors fine lifted - suspect an
  intermittent connection on one motor channel (GPIO16/17/18/19/22/23
  jumpers, L298N terminals, motor connectors). Driving paused until
  checked. Cliff mount v4: right printed, left printing.
- **Lesson/risk:** on a shared bus a stuck TFMini takes the MCP23008
  (motor direction pins, cliff inputs) with it. Decision: move the spinal
  cord to an ESP32 (two hardware I2C controllers -> TFMini on its own
  bus; spare UARTs) - roadmap item, not blocking.

### IR node (open)
- New IR LED and receiver installed. Receiver first sprayed ~25 frames/s:
  Enoch had a 100 ohm from OUT to GND (Claude's diagram was misread - the
  resistor is the LED's); then dead quiet. Rewired correctly, it decodes
  the remote cleanly, and near the dock it decodes the dock's beacon
  (NEC-style 9/4.5 ms header, payload 0xD6, ~5/s).
- Fresh captures vs the 09/28 set revealed the **frame format**: 6 bytes
  `68 cmd 00 FIELD FF sum`, sum = low byte of the first five. FIELD was
  0x13-0x14 on 09/28 and 0x07 on 10/02 on every button - a slow clock or
  counter. Command bytes: Fwd 2C, Back 7C, Left 3C, Right 6C, Home EF,
  Start/Stop 4F (two unlabelled buttons today: AD, 5D).
- Firmware: `eufy_send(command, field, carrier_hz)` builds any frame with
  the checksum; carrier_hz <0 generates the 38 kHz carrier in software.
  Receiver `rmt_symbols: 512` after a crash (log ring buffer, from the
  receiver loop) on the first loopback frame.
- **Transmitter still unproven:** nothing it sends is decoded by the
  node's own receiver (direct aim, bounce, 30-56 kHz sweep, software
  carrier, bigger LED), and the vacuum ignored Start/Stop in all four
  forms (hw/sw carrier x field 07/14). The dock beacon floods the
  receiver whenever the node is near the dock, so most loopbacks were
  contaminated. Next: loopback in another room; if still nothing,
  scope the LED pin.
- OTA gotcha: the ESP32 rolls back if it resets within 60 s of a new
  image - unplugging the node right after a flash undid it twice.

### BMS
- 3S 40A boards arrived; pad map in BOM. Deferred (Enoch: rover first).
- **Near miss, backing up.** Enoch asked for a test reverse toward the bench
  camera. Done in 0.3 s pulses with the marker as odometry and a stop at a
  known-safe distance - but the caster flipping on direction change dragged
  the rear sideways each pulse (+8, +11.5 deg drift), the third pulse
  turned the rover ~45 deg and lost the marker (the loop stopped on that,
  as designed), and it ended **with one wheel over the right-hand bench
  edge** - Enoch called it from the bench and lifted it back. Claude's
  error, precisely: the "look between pulses" used only the rover camera,
  which faces away from the direction of travel; marker distance measured
  how far back it had gone and nothing about the rear drifting sideways.
  The bench camera was the only sensor covering the space behind it and
  the script didn't consult it until the end. Rule added to `CLAUDE.md`:
  reverse is single short pulses with a bench-camera look before each one;
  the caster makes it unpredictable and there are no rear cliff sensors.
- **The rover is named Grover.** Enoch called Claude "the big blue Grover
  of your rover" (a Chef John-style rhyme); Claude read it as Sesame
  Street's Grover, Enoch liked the near/far fit, and the blue Makeblock
  rails sealed it.
- Power management, on Enoch's question before bed: firmware only refuses to
  drive under 9.3 V; idle draw still flattens a pack. For now he switches the
  pack off; deep-sleep and a hardware LVC are on the roadmap (3.2a/3.2b).

### Decisions, 2026-09-29 (Fable 5.1)

| Decision | Who | Why |
|---|---|---|
| Pivot at 100% motor duty (forward/backward stay 75%) | Claude proposed, Enoch approved the reflash | left pivots stalled under load at 75%; unloaded the tracks ran in sync, so it was torque margin, not wiring |
| Homing "arrived" = within the stop distance **and** either bearing <= 6 deg or lateral offset <= 30 mm; a lost marker right after a pulse at close range counts as arrived | Claude | at 170 mm the 160 mm marker overfills the frame; the loop was parking correctly and reporting failure |
| Per-direction adaptive pivot pulses, 1.0 s cap, stuck guard only after a pivot has maxed out | Claude | left and right needed different pulse lengths; the guard was quitting before the pulse had grown |
| Stop distance for the big marker stays 200 mm | Claude | the camera keeps the full marker in frame at ~215 mm; closer than that is the TFMini's job later |
| **Rebuild the chassis as the trike** (two motors + trailing caster) instead of tank tracks | Enoch raised the option without steering; Claude chose; Enoch is doing the rebuild | tank pivots skid the tracks sideways - the source of tonight's stiction and asymmetry; differential steering is unchanged so firmware and brain carry over |
| **Keep the D1 Mini + ESPHome; don't move to the kit's Me Orion board** | Enoch offered; Claude declined | no WiFi on the Orion, so the ESP stays anyway; the tested safety firmware would have to be rewritten for no gain |
| Adapter **strip** across the two front standoffs, not a full plate | Enoch asked which; Claude chose the strip | two posts 64 mm apart fully constrain a 30 g camera; a full plate waits until the TFMini and cliff sensors need mounting on the trike layout |
| Standoff slots oversized (4.5 mm, slotted 63-66 mm c-c) | Enoch's request | measurement was across hole edges; screw heads cover the play |
| Strip printed tonight without a fit check on the trike | Enoch: "if you're confident, you can print" | flat 20-minute part, 8.8 g; low cost to reprint if the trike moves the posts |
| Prints go through the print-warden, not the printer API | Enoch (and the homelab-helper session) | one gate for slicing, start permission, and monitoring; rule added to `CLAUDE.md` |
| Bench camera swap to the PTZ still deferred | Enoch, earlier tonight | finish testing on the current calibration first |
| Rewriting public git history to purge the earlier LAN-IP leak | **open - Enoch's call** | the tip is clean; a force-push touches a public repo, so not done without his say-so |

### Open for next session
1. Enoch: measure the board (six numbers in the `.scad` header), build the
   USB splice, print the marker page (`hardware/markers/`), answer the
   Roomba questions on issue #1.
2. Claude: set the `pcb_*`/`usb_*` values, re-render, re-slice via
   `hardware/slicing/slice.sh`, replace the placeholder files on the printer,
   then ask Enoch to start the print.
3. After mounting: fix camera orientation flags, drop stream resolution for
   latency, reflash.

---

## 2026-09-27 - Session 1 (continued): model switch, camera power decision

**Model:** Claude Opus 5.5 (`claude-opus-5-5`) - Enoch switched models
mid-session, after everything in the Sonnet 5 entry below. First real test of
the handoff: this model picked up from the conversation plus `CLAUDE.md`,
`JOURNAL.md`, and `BOM.md`.

### Guidance from Enoch
- Offered three ways to power the T-Camera and left the pick to Claude: a
  spare 3.7V Li-ion pack on the board's own battery connector, a 5-pin
  connector on the bottom of the board that can supply power, or cutting a
  spare USB cable.

### What happened
- Picked the spliced USB cable (buck converter at 5.0V -> micro-USB input).
  Why not the others:
  - **Separate 3.7V pack:** works electrically (it's what the board's IP5306
    charger is designed for), but it's a second battery to monitor and, in
    Phase 2, a second thing to recharge. One pack keeps one charging target,
    and the battery monitoring already calibrated covers it.
  - **5-pin bottom connector:** its pinout would need verifying before
    trusting it; USB is the documented, known-safe input.
- Wiring spec written up for Enoch (and logged in `BOM.md`): buck input on the
  L298N's +12V/GND terminals, downstream of the rover's power switch so the
  camera powers off with the rover; set and verify 5.0V output with a
  multimeter before connecting; verify USB wire colors by continuity; data
  wires unconnected and insulated; camera's JST battery connector left empty.

### Decisions
**Claude-driven:** choosing the power source, and the tap point downstream of
the power switch.

**Enoch-decided:** offering the options and delegating the choice; he does the
physical splice and wiring.

### Backup battery, and handoff to the next model

Enoch offered to add his spare 3.7V Li-ion pack as a *dedicated backup* on the
T-Camera's own JST connector, alongside USB power, so the camera survives a
main-pack depletion. Decided: yes, but after the USB path is built and
verified. The IP5306 runs the board from USB and charges the cell, then fails
over to the cell if USB drops. Caveat to measure, not guess: while charging,
the IP5306 can pull up to ~2A through the buck converter, all from the main
pack, which will cut drive time until the cell is full. Logged in `BOM.md`.

Enoch is switching models again and splicing the USB cable in the morning.
**Open work for the next session, explicitly authorized by Enoch:**
1. **Camera firmware.** Update the T-Camera's firmware for its new on-rover
   role, either as an ESPHome update or a rewrite from scratch, reflashing
   the device as needed (hostname `redcam`; the current config is
   `wrovercam.yaml` in the private ESPHome repo). Per `CLAUDE.md`, anything
   written goes in this repo with scripted installs.
2. **Camera mount (design + slice).** Constraints from Enoch:
   - It attaches to the Makeblock Starter Robot Kit chassis: a horizontal
     main plate with lots of regularly spaced holes, like a small pegboard.
     Research the kit's actual parts and hole spacing/screw size rather than
     guessing.
   - Account for the camera's orientation on the board. The current config
     sets `horizontal_mirror: true`, `vertical_flip: true`, and OLED
     `rotation: 180`, which suggests the board is currently mounted upside
     down. Once it's mounted upright on the rover, those flags probably need
     flipping.
   - The board also carries a PIR motion sensor and an OLED. The mount
     shouldn't block either, and ideally keeps the OLED readable.
   - Leave room for the micro-USB power lead and, later, the backup cell.
   - Printer: Sidewinder X4 Plus S1, PETG loaded. Claude slices; Enoch starts
     the print.
3. **Waiting on Enoch:** the USB splice and wiring (spec above), then the
   cliff sensors when they arrive.

**Claude-driven:** timing the backup cell after USB verification, and flagging
the charge-current draw on the main pack.
**Enoch-decided:** offering the backup cell, authorizing firmware work and
mount design, and the mount constraints.

---

## 2026-09-27 - Session 1: First drive + safety hardening

**Model:** Claude Sonnet 5 (`claude-sonnet-5`)

### Guidance from Enoch this session
- Mission: drive the rover around the garage workbench without falling off
  the edge (the right side of the camera view was flagged as the fall risk),
  using the existing fixed workbench camera as the only eyes. Update the
  ESPHome config as needed; more hardware can be added on request; an ESP32
  alternative controller was offered if it would help (later clarified as an
  ESP32-WROVER T-Camera already on hand, not the S3 variant).
- Explicitly told to prompt for any access needed (e.g. camera credentials)
  rather than guessing or working around it.
- Hardware context provided as it became relevant: 3x 18650 Li-ion cells,
  L298N dual H-bridge driving 2 motors, an MCP23008 GPIO expander used
  specifically because the D1 Mini didn't have enough spare pins to drive the
  L298N directly, and the L298N's onboard 5V regulator (rated ~0.5A) is what
  powers the D1 Mini - fed from the raw battery rail, not a separate supply.
- Firmware/hardware direction largely left to Claude's judgment ("optimize
  the config... or write custom firmware... let me know if you want me to add
  components").
- Longer-term mission shape: solve the workbench/fall-hazard problem solidly
  first, *then* expand to roaming the whole house - a signal that navigation
  safety now should anticipate that later, higher-stakes phase.
- Wanted a public GitHub repo to track and show off progress, with a hard
  requirement to scrub all secrets/IPs/usernames/passwords/WiFi SSIDs before
  anything is published.
- Wanted a link to that repo added to the workbench project's spot on the
  Home Assistant dashboard.
- Wanted this journal: dated, model-tagged, resumable across sessions *and*
  model switches, summarizing the guidance given, and honest about
  Claude-driven vs. Enoch-decided calls.
- Wanted a maintained BOM (what's actually in the design) and a shopping list
  (what Claude needs Enoch to acquire), with a standing **$100 budget** for
  anything not already in Enoch's inventory - documented in the repo.

### What happened
- Got camera access working: the workbench ONVIF camera (Thingino firmware)
  needed Basic auth; the saved username turned out to be wrong - Thingino's
  login is always `root`, regardless of what's saved. Also found that the
  camera's `preview.cgi` returns an HTML viewer page, not an image; the real
  snapshot endpoint is `image.cgi`.
- The first snapshot was pitch black; turned on the garage workbench light
  via Home Assistant before continuing.
- Drove the rover directly over ESPHome's **native API**, bypassing Home
  Assistant entirely - its connection to this device turned out to be stale
  (entities showing unavailable despite the device being online). Confirmed
  all five existing services work: `forward`, `backward`, `left`, `right`
  (the latter two are in-place pivot turns), `stop`. Drove forward a full
  bench-length, pivoted, backed off from some bench clutter it was closing in
  on, and pivoted the other way - staying clear of the flagged edge the whole
  time.
- Identified a real safety gap: nothing stopped the motors if whatever was
  driving the rover crashed or the network dropped mid-command. Added two
  protections to the firmware:
  - **Command watchdog** - any drive command auto-stops if not refreshed
    within 1.5s.
  - **Disconnect-triggered stop** - motors stop the instant the controlling
    API client disconnects, for any reason.
  - Verified the second one for real: fired `forward`, disconnected without
    ever sending `stop`, reconnected two seconds later, and confirmed the
    rover had already stopped itself.
- Scaffolded two more safety layers into the firmware ahead of the hardware
  existing, so they activate the moment it's wired in with no further
  firmware changes:
  - **Cliff detection** - two IR reflectance sensors on the GPIO expander's
    two free pins; forward/turn commands refuse to run while either sensor
    reports no surface underneath (backward stays allowed, so it can always
    retreat from an edge).
  - **Battery cutoff** - a voltage sensor on the D1 Mini's one analog pin;
    drive commands refuse below ~9.3V pack voltage, recovering at 9.6V.
- Caught and fixed a config bug along the way: adding the new battery sensor
  block had silently replaced - rather than merged with - the device's
  existing uptime/WiFi-signal sensors, because of how this file combines
  shared config fragments. Restored them. (Noted, but left alone as
  out-of-scope: the same underlying issue already affected two *other*
  sensors from before this session.)
- Built and pushed the public repo, `github.com/moellere/rover`: a
  mission-log README, a reference copy of the firmware, and three sanitized
  scripts (a drive CLI, the disconnect-safety test, and a camera-snapshot
  helper). Everything was scanned for IPs/hostnames/paths/credentials before
  the initial push. Creating the actual GitHub repo needed Enoch to run the
  command himself - a safety guardrail blocks Claude from creating public-
  facing surfaces unilaterally.
- Added a link to the repo on the Home Assistant "Garage" dashboard section,
  next to the existing workbench-light control.

### Decisions

**Claude-driven** (identified, designed, or implemented without being asked
for that specific thing):
- Diagnosing the stale Home Assistant connection and switching to direct
  native-API control instead of troubleshooting HA further.
- Identifying the no-timeout/no-disconnect-handling safety gap and designing
  the watchdog + disconnect-stop fix.
- Designing the cliff-sensor and battery-cutoff scaffolding: pin choices,
  voltage thresholds, and which drive directions each guard blocks (backward
  deliberately stays allowed under a cliff condition).
- Catching and fixing the sensor-merge config bug.
- The repo's structure, contents, and sanitization pass.

**Enoch-decided:**
- The mission and its phases (workbench first, house-wide later).
- Battery pack configuration (3S) and the wiring/tap-point clarifications for
  the divider.
- Confirming "write the cliff-sensor config now" and "3S, ~12.6V" when asked
  directly via a scoped question.
- Repo name and visibility (`rover`, public) and what it should contain.
- Actually creating the GitHub repo (Claude was blocked from doing this
  unilaterally).
- This journal/BOM/budget system itself, including the $100 budget policy.

### Update, same session - divider wired, IR sensors ordered

Enoch confirmed the exact chassis (a Makeblock Starter Robot Kit, tank
configuration) for the BOM, wired the battery-voltage divider per the
confirmed schematic (100kΩ/27kΩ from the L298N's +12V terminal to the D1
Mini's A0), and ordered the two IR cliff sensors himself - directly, not
against Claude's $100 budget. BOM updated accordingly: the divider moves to
Installed, the cliff sensors show as Ordered. Next step on the battery side
is calibrating the `multiply` constant in `rover.yaml` against a real
multimeter reading, once convenient.

Enoch also said this session is ending here for now, with a model switch to
follow - a first real test of whether this journal actually does its job of
letting a different model pick things up cleanly.

### Update, same session - battery sensor calibrated

Before wrapping up, Enoch asked whether the voltage reading had actually been
tested - it hadn't; the sensor had only ever been read with the placeholder
`multiply: 15.0`. Read it live: 11.3232V. Enoch measured the pack directly
with a multimeter: 11.79V. Solved for the correct factor
(`11.79 / (11.3232 / 15.0) = 15.618`), updated `rover.yaml`, recompiled,
OTA-flashed, and re-read the sensor: 11.77V - within noise of the multimeter
reading. Battery monitoring is now fully installed and verified accurate, not
just wired.

### Update, same session - project constraints, next milestone, documentation policy

Enoch turns didn't actually end the session yet - three more rounds of
guidance came in before the model switch:

1. Asked what Claude would tackle next (besides the already-ordered cliff
   sensors), and laid out the standing constraints this project operates
   under: never harm a person or animal, never intentionally damage property
   or equipment, stay within budget, break no laws knowingly - and within
   those limits, expand capabilities freely for experimentation, science,
   and fun. Parts requests go through Enoch; anything he already has doesn't
   count against budget, anything he doesn't goes on the shopping list and
   draws the budget down. Claude is expected to research parts and current
   pricing before asking for a purchase. Budget increases happen at Enoch's
   discretion as milestones are hit. 3D printing is available (a Sidewinder
   X4 Plus S1, currently loaded with PETG, with a camera attached for
   monitoring) - Claude designs and slices, Enoch loads/starts the actual
   print. Physical building/soldering gets discussed before either of them
   just does it.
   - Claude's pick for "what's next": mount the already-owned, currently
     unused ESP32-WROVER T-Camera on the rover for onboard vision - zero
     budget cost, and necessary before Phase 3 (the fixed workbench camera
     won't help once the rover leaves that room). Flagged one open question
     before committing: the L298N's 5V regulator is already tight at 0.5A,
     so the camera almost certainly needs its own power path rather than
     sharing that rail - asked Enoch to identify the T-Camera board's exact
     input spec.
2. Enoch confirmed he has buck converters in inventory already, covering
   that power-path need at no budget cost if one turns out to be necessary -
   specifically LM2596 adjustable modules (4.5-40V in, 1.25-37V out, ~2-3A),
   comfortably able to run the pack straight down to whatever the T-Camera
   needs. Logged in `BOM.md`. Still waiting on the T-Camera's exact input
   spec before setting the output voltage - 5V is the likely answer but
   unconfirmed.
3. Added a documentation/software policy: keep the journal, BOM, and other
   docs current *as changes happen*, not after the fact. Prefer open-source
   software over writing new code; if something has to be written, it goes
   in this repo; any external software this project depends on gets a
   scripted install, not manual instructions. The explicit goal: someone
   else should be able to clone this repo and actually reproduce the build.

Created `CLAUDE.md` at the repo root to hold all of this as a standing
rulebook - it's auto-loaded by Claude Code as project instructions for any
future session in this repo, on any model, which directly serves the
"pick up where we left off across model switches" goal this whole
journal/BOM/CLAUDE.md system exists for. Updated `BOM.md` with an "in
progress" section tracking the camera-mount investigation (buck converter,
3D-printed mount) ahead of it becoming a full BOM line.

**Claude-driven:** picking the onboard-camera milestone and its
justification; identifying the shared-regulator power risk before it caused
a problem; the `CLAUDE.md` structure and what it captures.

**Enoch-decided:** the constraints themselves, the budget mechanics, the 3D
printing and physical-assembly workflow, confirming buck converters are on
hand, and the documentation/software policy in full.

### Update, same session - identified the camera, researched its power spec

Enoch identified the exact board: a TTGO T-Camera, ESP32-WROVER-B,
OV2640 V1.7, already on the network (hostname `redcam`) and reflashable.
Turned out this isn't the unused spare assumed earlier - it's
an *existing, working* ESPHome device (`wrovercam.yaml` in the private
config repo): camera streaming at SXGA over its own web server (ports 8080
stream / 8081 snapshot), a 0.96" OLED showing motion/time/IP, a PIR motion
sensor, and a scheduled daily reboot. Currently deployed fixed and
USB-powered elsewhere - moving it to the rover means solving power for a
battery-mounted context instead.

Researched the board before wiring anything to it (avoided a real risk:
guessing wrong here could fry the board). Finding: it has an onboard IP5306
power-management chip whose battery JST connector expects a **single-cell
3.7V LiPo** - directly wiring the rover's 3S pack (9-12.6V) there would
damage the charge IC. The board also accepts power via **micro-USB (5V)**,
a safe, standard, documented path. Plan: LM2596 buck converter set to 5.0V
(verify with a multimeter first) feeding into the T-Camera's micro-USB
input, not its battery connector. Logged in `BOM.md`, including the one
remaining open decision: splice a spare USB cable (free, destructive) vs.
buy a small USB breakout/screw-terminal adapter (~$1-2, clean) to actually
deliver that 5V into the port - left for Enoch per the "discuss before
building" rule in `CLAUDE.md`.

Also noted: the rover itself is powered off for the night (batteries saved,
not a firmware/config state).

**Claude-driven:** researching the board's real power spec before acting on
an assumption, and catching the JST/LiPo-connector risk before it became a
mistake.

**Enoch-decided:** identifying the exact board and confirming it's
reflashable; still pending his choice on cable-splice vs. breakout adapter.

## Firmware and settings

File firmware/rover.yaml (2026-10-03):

# Reference copy - the canonical, live-flashed version of this file lives in a
# private homelab ESPHome config repo (which is where `!include common/...` and
# `!secret api_key` actually resolve from). This copy won't compile standalone;
# it's here for history/documentation of the rover project.
substitutions:
  devicename: rover

esp8266:
  board: d1_mini
  
esphome:
  name: $devicename
  on_boot:
      - output.set_level:
          id: left_pwm
          level: 0%
      - output.set_level:
          id: right_pwm
          level: 0%
      - output.turn_off: left_forward_pin
      - output.turn_off: right_forward_pin
      - output.turn_off: left_reverse_pin
      - output.turn_off: right_reverse_pin

<<: !include common/base.yaml
<<: !include common/sensor.yaml


time:
  - platform: homeassistant
    id: homeassistant_time

globals:
  - id: last_command_ms
    type: uint32_t
    restore_value: no
    initial_value: '0'
  - id: cliff_detected
    type: bool
    restore_value: no
    initial_value: 'false'
  - id: battery_ok
    type: bool
    restore_value: no
    initial_value: 'true'
  # TFMini forward LiDAR: true while something is inside the "Obstacle stop"
  # distance. Holds its last state through invalid frames, because the
  # TFMini goes invalid under 30 cm - an object that crossed the threshold
  # and kept coming must not clear the guard by getting too close to see.
  - id: obstacle_ahead
    type: bool
    restore_value: no
    initial_value: 'false'
  - id: tfmini_errors
    type: int
    restore_value: no
    initial_value: '0'

# Pin map for awning
#D0: 
#D1: SCL - MCP23008 Pin 1
#D2: SDA - MCP23008 Pin 2
#D5: left_pwm
#D6: right_pwm
#MCP0: Connected to L298N IN1
#MCP1: Connected to L298N IN2 
#MCP2: Connected to L298N IN3
#MCP3: Connected to L298N IN4
#MCP4:
#MCP5: 
#MCP6: 
#MCP7: 



# Stop = brief dynamic brake, then coast. Both inputs of each L298N bridge
# high with EN high shorts the motor winding; ~150 ms is enough to kill the
# momentum at cruise (coast alone was ~8 cm). Then everything releases so
# nothing sits in a braked short. Every stop path uses this - watchdog,
# disconnect, cliff, battery, the stop action. The "Brake on stop" switch
# gates the brake phase; it boots OFF (a 2026-09-29 A/B showed no measurable
# effect on short pulses, and the ESP8266 doesn't persist switch state
# across power cycles anyway). The stop itself always happens.
# Pins go to brake before EN goes to 100%, so there is never a full-duty
# instant in the old drive direction.
script:
  - id: motor_stop
    mode: restart
    then:
      - if:
          condition:
            switch.is_on: brake_on_stop
          then:
            - output.turn_on: left_forward_pin
            - output.turn_on: left_reverse_pin
            - output.turn_on: right_forward_pin
            - output.turn_on: right_reverse_pin
            - output.set_level:
                id: left_pwm
                level: 100%
            - output.set_level:
                id: right_pwm
                level: 100%
            - delay: 150ms
      - output.set_level:
          id: left_pwm
          level: 0%
      - output.set_level:
          id: right_pwm
          level: 0%
      - output.turn_off: left_forward_pin
      - output.turn_off: right_forward_pin
      - output.turn_off: left_reverse_pin
      - output.turn_off: right_reverse_pin
      - text_sensor.template.publish:
          id: motion_status
          state: "Stopped"
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

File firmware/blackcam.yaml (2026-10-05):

# Reference copy - the canonical, live-flashed version of this file lives in a
# private homelab ESPHome config repo (which is where `!include common/...` and
# `!secret api_key` actually resolve from). This copy won't compile standalone;
# it's here for history/documentation of the rover project.
# blackcam: the Eufy RoboVac's lid board (2026-10-04) - camera + IR remote.
# T-Camera (ESP32-WROVER), same family as redcam; powered from its bottom
# header 5V (this unit accepts it; redcam does not).
#
# IR: IO22 -> 1k -> NPN base, emitter -> GND, 5V -> 33R -> 940 nm LED ->
# collector (~105 mA). LED aimed down at the Eufy's IR window.
# Frame: 68 CMD HH MM 5C SUM (HH 12-h hour, MM minute, SUM = low byte of
# the first five); the vacuum ignores stale times, so frames are stamped
# from SNTP. Hardware RMT 38 kHz carrier. Cmd: Fwd 2C, Back 7C, Left 3C,
# Right 6C, Home EF, Start/Stop 4F.
substitutions:
  devicename: blackcam
  
esphome:
  name: $devicename

esp32:
  board: ttgo-t-beam
  framework:
    type: esp-idf

<<: !include common/base.yaml
<<: !include common/sensor.yaml

# ESP32-WROVER-B: 8 MB PSRAM, needed for the camera frame buffers at this rate.
psram:

# Camera
esp32_camera:
  external_clock:
    pin: GPIO32
    frequency: 20MHz
  # ESPHome 2026.x: the camera's SCCB bus is a normal i2c bus now (see `i2c:`)
  i2c_id: cam_sccb
  data_pins: [GPIO5, GPIO14, GPIO4, GPIO15, GPIO18, GPIO23, GPIO36, GPIO39]
  vsync_pin: GPIO27
  href_pin: GPIO25
  pixel_clock_pin: GPIO19
  power_down_pin: GPIO26
  # Image settings
  name: $devicename Camera
  # ...
  resolution: SXGA
  horizontal_mirror: true
  vertical_flip: true
  # The rover brain polls the snapshot endpoint between drive pulses; the
  # default idle rate (0.1 fps) serves frames up to 10 s stale. Keep capturing.
  max_framerate: 10 fps
  idle_framerate: 1 fps

i2c:
  # IO21/IO22 were the OLED/IP5306 bus; the OLED is dropped and IO22 drives
  # the IR LED (see remote_transmitter). IO21 is left alone, so no I2C START
  # can occur on that bus.
  - id: cam_sccb
    sda: GPIO13
    scl: GPIO12
    scan: false

#Motion Sensor    
binary_sensor:
  - platform: gpio
    pin: GPIO33
    name: "Blackcam Motion"
    id: blackcam_motion
    device_class: motion
  - platform: gpio
    pin:
      number: GPIO34
      mode: INPUT
    name: "Blackcam Button"
    filters:
      - invert:

switch:
  - platform: restart
    name: "Blackcam Restart"
    id: "reboot"

# Example configuration entry
esp32_camera_web_server:
  - port: 8080
    mode: stream
  - port: 8081
    mode: snapshot
    
time:
  - platform: sntp
    id: sntptime
    servers:
      - 0.pool.ntp.org
    on_time:
      # Every morning on weekdays
      - seconds: 0
        minutes: 30
        hours: 1
        then:
          - switch.toggle: reboot

remote_transmitter:
  pin: GPIO22
  carrier_duty_percent: 50%
  rmt_symbols: 192

script:
  - id: eufy_tx
    # Commands are fixed nudges that finish within ~1 s (measured 2026-10-05),
    # so nothing is ever left "running" for a disconnect watchdog to stop.
    # The real hazard for a vision loop is a stale backlog firing late, so
    # cap the queue: one sending, one waiting, extras dropped.
    mode: queued
    max_runs: 2
    parameters:
      command: int
    then:
      - remote_transmitter.transmit_raw:
          carrier_frequency: 38kHz
          code: !lambda |-
            auto now = id(sntptime).now();
            uint8_t hh = 0, mm = 0;
            if (now.is_valid()) { hh = now.hour % 12; if (hh == 0) hh = 12; mm = now.minute; }
            else ESP_LOGW("eufy", "no SNTP time yet - the vacuum will probably ignore this");
            uint8_t b[6] = {0x68, (uint8_t) command, hh, mm, 0x5C, 0};
            b[5] = (uint8_t) (b[0] + b[1] + b[2] + b[3] + b[4]);
            std::vector<int32_t> v;
            v.push_back(2974); v.push_back(-3053);
            for (int i = 0; i < 6; i++)
              for (int bit = 7; bit >= 0; bit--) {
                v.push_back(474);
                v.push_back((b[i] >> bit) & 1 ? -1553 : -526);
              }
            v.push_back(447);
            ESP_LOGI("eufy", "send %02X %02X %02X %02X %02X %02X", b[0], b[1], b[2], b[3], b[4], b[5]);
            return v;
          repeat:
            times: 3
            wait_time: 40ms

api:
  actions:
    - action: eufy_command
      variables:
        command: int
      then:
        - script.execute:
            id: eufy_tx
            command: !lambda 'return command;'
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

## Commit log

2026-09-27 Initial commit: rover project log, control scripts, firmware reference
    Documents the workbench rover build: ESPHome firmware (safety watchdog,
    disconnect-triggered stop, cliff-sensor and battery-monitoring scaffolding),
    scripts for direct native-API control and a workbench camera snapshot, and
    progress photos from the first drive session.
2026-09-27 Add project journal and BOM/shopping-list tracking
    Journal captures per-session guidance, what happened, and a Claude-driven
    vs Enoch-decided breakdown, tagged with the model used, so work can resume
    across sessions and model switches. BOM/shopping list tracks what's in the
    current build vs what's still needed, against a standing $100 budget.
2026-09-27 Update BOM: chassis kit name, divider installed, cliff sensors ordered
    Battery-voltage divider is now physically wired (moved to Installed in the
    BOM). IR cliff sensors are ordered directly by Enoch and explicitly excluded
    from Claude's $100 budget tracking. Also names the exact chassis (Makeblock
    Starter Robot Kit, tank configuration) instead of a generic description.
2026-09-27 Calibrate battery voltage sensor against a multimeter reading
    Read the sensor for the first time since the divider was wired (11.3232V at
    the placeholder multiply:15.0), compared against a real multimeter reading
    of the pack (11.79V), solved for the correct factor (15.618), flashed it,
    and re-verified: 11.77V, within noise of the multimeter. Battery monitoring
    is now verified accurate, not just wired.
    [rover.yaml]
2026-09-27 Add CLAUDE.md project rulebook; log constraints and doc/software policy
    CLAUDE.md captures the standing rules this project operates under (mission,
    hard constraints, budget/parts policy, 3D-printing and assembly workflow,
    software policy, documentation policy) as a file Claude Code auto-loads for
    any future session in this repo, on any model - the actual mechanism for
    resuming work across model switches. Journal and BOM updated to match:
    next milestone (onboard ESP32-WROVER camera, pending power-path check),
    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
2026-09-27 Identify buck converter part for camera power path (LM2596)
    Enoch's inventory buck converters are LM2596 adjustable modules - logged
    the specific part and specs in BOM.md. Output voltage still pending
    confirmation of the T-Camera's actual input requirement.
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2026-09-27 Camera mount design, no-root design/slicing toolchain, session 2 journal
    Adds hardware/camera-mount.scad (parametric cradle for the T-Camera on the
    Makeblock 8mm M4 grid, 10 deg down-tilt, USB window) with its STL and a
    README; scripts/install-tools.sh installs OpenSCAD and OrcaSlicer as
    extracted AppImages and documents the one sudo apt line Orca needs.
    Journal records the Fable 5.1 session, the redcam flash permission, print
    preferences (tree supports, no brim), the token-budget rule, and the
    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
    [camera-mount.scad, camera-mount.stl]
2026-09-27 Cradle redesign for bottom-edge USB; slicing pipeline and first dry-run print files
    The T-Camera's micro-USB and 5-pin connector are on the board's bottom
    edge, so the cradle now floats on a pedestal with an open gap for the plug
    and a rear cable window. Adds scripts/orca_flatten_preset.py (OrcaSlicer's
    CLI rejects inheriting presets, so flatten them), hardware/slicing/ with the
    house rules (no brim, tree supports auto) and a one-command slice.sh, and
    the first sliced output - placeholder dimensions, labelled as such.
    Claude-Session: https://claude.ai/code/session_01BySkWE8gwvNzrBFboHZqhL
    [camera-mount.scad, camera-mount.stl, camera-mount_v1_PLACEHOLDER-DIMS.3mf]
2026-09-27 Journal/BOM: bottom-USB redesign, slicing pipeline, placeholder print upload
    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
2026-09-27 Roadmap: adopt the Roomba (issue #1) as the house chassis, conditionally
    The Open Interface provides docking+charging, four cliff sensors, bump,
    encoders and battery telemetry, retiring the dock/charger/BMS build for
    the house robot. Makeblock rover stays the bench platform. Adds Tier 2R to
    the roadmap, a candidate section to the BOM, and the decision to the
    journal; full reasoning is on the issue.
    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
2026-09-27 Add a printable 7-pin mini-DIN plug body for the Roomba OI port
    Enoch has no cable; this holds seven solid-core wires at the mini-DIN-7
    pin positions (traced from the standard diagram, scaled to the 9.5 mm
    face) with a keyed insert and a grip. Fit-critical values are parameters
    for a test-print iteration.
    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
    [roomba-minidin-plug.scad, roomba-minidin-plug.stl]
2026-09-27 Slice a test-fit print of the mini-DIN plug; upload to the printer
    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
    [roomba-minidin-plug_v1_TESTFIT.3mf]
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2026-09-27 Roomba is gone: pivot the house-chassis plan to the Eufy RoboVac 12 over IR
    Shelve the mini-DIN plug with the two fixes from the test print (inset key
    groove, larger wire holes). Roadmap Tier 2R becomes 2E: drive the RoboVac 12
    with an ESP-hosted IR transmitter using published Pronto codes, keeping its
    native docking/charging/cliff/bumper behaviour; telemetry comes later from
    inside the shell. BOM and journal updated.
    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
    [roomba-minidin-plug.scad, roomba-minidin-plug.stl]
2026-09-27 Plug: keep insulation holes off the pin pitch (manifold fix)
    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
    [roomba-minidin-plug.scad, roomba-minidin-plug.stl]
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2026-09-27 Update PCB dimensions for camera mount
    [camera-mount.scad]
2026-09-27 Camera mount v2: re-rendered and re-sliced with measured board dimensions
    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
    [camera-mount.stl, camera-mount_v1_PLACEHOLDER-DIMS.3mf, camera-mount_v2.3mf]
2026-09-27 Camera mount v3: straight-down cable slot through the base
    The USB lead runs in line with the board, straight down from the bottom
    edge - not bent backward. Adds a base pass-through aligned with a Makeblock
    plate hole; the rear window stays as an alternative exit.
    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
    [camera-mount.scad, camera-mount.stl, camera-mount_v2.3mf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]
2026-09-27 Eufy IR node live with codes captured from the RoboVac 12's own remote
    The published 11S codes share the protocol and address prefix but not the
    command payloads; the six captured codes replace them. Docs, BOM, roadmap
    and the reflash permission for eufy-ir updated.
    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
2026-09-27 Camera mount v4: bottom tabs and front lips step inward, not outward
    Enoch found on the v3 print that the tabs sat under the side walls and the
    lips on top of them - an outward offset applied to both sides - so nothing
    supported the board's bottom edge or held its front face. Both now step
    inward from the rails by their width.
    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
    [camera-mount.scad, camera-mount.stl, camera-mount_v3.3mf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]
2026-09-27 Camera mount v5: front lips only at the four corners
    Enoch's photos of the v3 print with the board in place show buttons at the
    board edges and the OLED nearly full-width, so full-length front lips would
    collide. Lips are now 4.5 mm corner tabs (upper ones chamfered for tilt-in
    insertion); the component-free end zones need confirming before printing.
    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
    [camera-mount.scad, camera-mount.stl, camera-mount_v4.3mf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]
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2026-09-29 Journal/BOM/roadmap: Eufy IR failure traced to dead IR LEDs; replacements on order
    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
2026-09-29 Markers: add a 160 mm id-1 page for long range (id 0 too small for the rover cam at 50 in)
    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
2026-09-29 MILESTONE: visual homing works; shorter close-in steps; TFMini on the plan
    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
2026-09-29 Journal: bench camera swap agreed, deferred until testing is done
    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
2026-09-29 Homing: stop after three no-progress pulses instead of grinding (stuck guard)
    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
2026-09-29 rover firmware: pivots at 100% duty; homing initial pivot 0.15 s
    Left pivots stalled under load at 75% while right pivots bit at 0.25 s;
    unloaded both tracks ran in sync, so it was torque margin, not wiring.
    At 100% a 0.3 s pivot turns ~24 deg in either direction.
    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
    [rover.yaml]
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2026-09-29 hardware: camera adapter strip v1 (64 mm standoffs); trike rebuild decision; roadmap tier 0 update
    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
    [camera-strip.scad, camera-strip_v1.3mf]
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2026-09-29 trike: firmware ref (channel remap, duty sliders); homing retries transient camera errors, 1.2 s frame gap
    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
    [rover.yaml]
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2026-09-29 near miss: one wheel over; the real error was reversing without the bench camera in the loop
    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
2026-09-29 TFMini bracket: design + STL, staged on print-warden; docs
    [tfmini-bracket.scad, tfmini-bracket.stl]
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2026-10-03 TFMini reading: I2C fixes (repeated start, 100 kHz, stretch limit); journal for 10/01-10/03; roadmap: ESP32 spinal cord
    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
    [rover.yaml]
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2026-10-03 cliff sensor mount: parametric draft (needs beam height + module dims)
    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
    [cliff-mount-left.stl, cliff-mount-right.stl, cliff-mount.scad]
2026-10-03 cliff mounts: dimensions set, both sides staged on print-warden
    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
    [cliff-mount-left.stl, cliff-mount-right.stl, cliff-mount.scad]
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2026-10-03 rover32 live: polarity fix, 0xFFFF invalid; docs
    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
    [rover32.yaml]
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2026-10-03 cliff mount v2: side ribs past the screw; both sides staged
    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
    [cliff-mount-left.stl, cliff-mount-right.stl, cliff-mount.scad]
2026-10-03 cliff mount v3: ribs reach past the board edges
    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
    [cliff-mount-left.stl, cliff-mount-right.stl, cliff-mount.scad]
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2026-10-04 cliff mount v4: sensor on the tyre centreline 65 mm ahead of the axle, slim spine+arm; staged
    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
    [cliff-mount-left.stl, cliff-mount-right.stl, cliff-mount.scad]
2026-10-04 journal: first floor run, wall bump, guard fix
    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
    [rover32.yaml]
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2026-10-05 rover32 reference: battery guard fix
    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
    [rover32.yaml]
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2026-10-05 journal: swing traced to the swivel caster; guard and battery fixes verified
    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
2026-10-05 caster skid: fixed domed skid to replace the swivel caster; staged
    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
    [caster-skid.scad, caster-skid.stl]
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2026-10-05 fix: the 'hinge' is Enoch's solder fan
    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
2026-10-05 brain: locate (overhead pose from a top marker), eufy tool + camera, HTTP transport, Dockerfile; fix install-brain.sh; id-2 top marker page
    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
2026-10-05 blackcam: cap IR queue; journal: Eufy commands are fixed nudges
    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
    [blackcam.yaml]
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2026-10-18 rover32: ramped motion engine (min duty / accel / decel), on-board timed move, set_speeds, halt
    Replaces the 100 ms 100% kick start with a speed profile executed on the
    ESP32: every command sets a signed target duty per wheel and a 20 ms loop
    ramps the live duty toward it (jump to Min duty from rest, then Accel
    time up; Decel time down). Guards never ramp - watchdog, disconnect,
    cliff, obstacle and battery all still stop at once (halt). New API
    actions: move(direction, ms, duty) timed on-board, set_speeds(left,
    right) for steering loops, halt. Brain: drive() uses move when present,
    set_speeds()/halt() in the client, set_ramp tool, ramp in status.
    Flashed OTA 2026-10-18; untested on the bench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
2026-10-18 journal/BOM: fall damage - T-Camera, rear plate, skid bracket
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2026-10-18 hardware: rear-leg.scad draft (printed bracket + skid in one piece); README on the camera cradle failure
    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
2026-10-18 battery cradle: BMS flush with the holder's end, full-height lead slot; window fix
    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
2026-10-18 battery cradle: 2 mm end clearance for the balance-lead wraps
    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
2026-10-19 journal: tank front end differs - cliff mounts and TFMini bracket to be redesigned
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2026-10-19 rover32: gyro calibration requires quiet readings (restart on >3 dps spread); gyro wired, flashed, drift measured
    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
2026-10-19 docs: TFMini bracket and cliff mounts fitted to the tank's deck-plate front edge; no front bracket redesign needed
    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
2026-10-23 rover32: gyro sign flipped (module Z-down on the tank), min/pivot duty defaults 75/90 for the tank
    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
2026-10-24 print_marker: PWG raster + full media-col (Canon support code 2110 behind every 'other-error'); ids 2 and 0 printed
    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
2026-10-24 brain: dock_approach chains overhead go_to (stops 45 cm out) with onboard home_to_marker; journal: paper-under-track stall, marker cap
    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
2026-10-24 dock_approach reaches the upright marker; steer: fixed post-move wait + spaced frames; homing: tank step distances, wider lost-close arrival
    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
2026-10-24 journal: deck plate grid corrected - 4 mm holes, ~9 mm pitch
    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
2026-10-24 journal: pad bracket as a strap under the cliff mount bolts, wide pad for lateral tolerance
    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
2026-10-24 journal: the pad becomes a second wing on the cliff mount (Enoch's suggestion); warp inconsequential; heights derived
    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
2026-10-24 dock: on the base, square, 68 mm short - the black base trips the cliff guard; creep reports cliffs and lengthens after a stall; journal
    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
2026-10-26 brain: dock re-squares after a steer correction and gives up on failed small pivots after two
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2026-10-26 roadmap, BOM: hardware revision order (reboot fix, fuse, wider pads, rear cliffs, ramp, DRV8871 candidate)
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2026-10-26 brain: dock treats a stall at the bumper as docked and confirms charging by the voltage step
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2026-10-26 firmware: WS2812B chain on GPIO4 and a reset-reason sensor (flashed OTA); journal
2026-10-26 hardware: headlight clip v2 - LED pockets 1 mm looser, softer snap rim; printing f6c0ac8158
2026-10-26 hardware: headlight clip v3 - teardrop pockets, no snap rim, 12 and 13 mm variants printing
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2026-10-26 hardware: headlight clip - v3 slightly loose (glued, in use); default pocket 11.7 mm
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2026-10-26 carrier: shield + half-breadboard plate, two-rail pin swap (gyro 25/26, TFMini 21/16), no expander for safety lines
2026-10-26 carrier: no pin swap - V leads cross rails instead (Enoch)
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2026-10-26 carrier: pack lifts out (not slides); lowered cradle needs BMS clearance and a new base around the rear posts
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2026-10-26 carrier: chassis from the kit manual (BaseBracket deck, M4x30 studs); shorter measurement list
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2026-10-31 driver tray: DRV8871 holes 3.2 mm, 16.2 mm centres (Enoch's correction); printed v1 still fits via the slots
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2026-10-31 firmware: DRV8871 x2 replace the L298N - PWM on IN1/IN2 (slow decay), brake both high; GPIO16/17 freed. Flashed OTA (motors disconnected)
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2026-10-31 carrier: Freenove not in hand - base board open; driver swap on the existing breadboard
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2026-10-31 carrier: wiring.md - pre-swap layout from photos, certain pins, TODO rows to confirm at teardown
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2026-10-31 driver tray v2: Wago bus pockets merged at the front; buck hole diagonal fixed (Enoch)
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2026-10-31 carrier: battery behind the acrylic, fixed top plate on the posts (Enoch); height-vs-width choice noted
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2026-10-31 battery tray: fix mirrored output (y-rearward frame made +x Grover's left); printed v2 has tabs and BMS window swapped
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2026-10-31 JOURNAL: the carrier rework (DRV8871s, power deck, battery tray, top plate v2)
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2026-10-31 JOURNAL: photos from 10-26 (LED chain) and the 10-31 carrier rework (metadata stripped)
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2026-10-31 JOURNAL: status strip cause - right dot's Dout shorted to 5 V
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2026-11-01 JOURNAL: the VM short reached the whole 5 V bus
2026-11-01 JOURNAL: camera survived the 5 V bus short too
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2026-11-01 battery sense on GPIO8 (GPIO1 terminal welded to GND); one-track test passed; boot twitch noted
2026-11-01 JOURNAL: battery divider ratio wrong (0.32) - ADC saturated, GPIO8 over-voltage
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2026-11-01 JOURNAL: boot twitch only on hardware reset (power-on / EN), not soft resets
2026-11-01 JOURNAL: bench re-commissioning - guards pass, left motor swapped in firmware, straight drives
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2026-11-01 JOURNAL: first dock on the S3 - aligned to 2 mm, cliff guard stopped it 34 mm short on the dark base
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2026-11-01 JOURNAL: faulty front-right cliff sensor swapped; both read floor on the dock
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2026-11-02 JOURNAL: ramp fitted; duties 75/90 -> 60/60 for the DRV8871s (aggressive moves, small pivots cut short)
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2026-11-02 JOURNAL: turn(30) became a 70 cm forward arc - left track not reversing; bench driving suspended
2026-11-02 JOURNAL: left motor loose on its gearbox (10-18 fall) - likely cause of the failed pivots
2026-11-02 JOURNAL: left motor fixed, reverses cleanly
2026-11-02 brain: edge keep-out (no move within 130 mm of the open edge, overhead frame); fix go_to cliff check (at_lip belongs to dock)
2026-11-02 JOURNAL: clean autonomous dock and charge (contact 1 mm short); run log; edge keep-out noted
2026-11-02 brain: dock() undocks first - reverses straight out along the axis in 0.4 s pulses when starting within 430 mm
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2026-11-07 docs: currency pass - own journal entry for 10-31..11-03 with corrections, status block, local dates, rear bar printed, carrier status
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2026-11-07 brain: turn margin (big turns need 200 mm from the edge - a 180 deg go_to pivot drifted to 91 mm); trials keep undock/go_to/face logs; JOURNAL run 3
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2026-11-07 JOURNAL: flat cliff boards in the nose module; servo firmware; one faulty S51 replaced
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2026-11-07 hardware: nose module - TCRT5000 turned (long axis across the board = fore-aft, per Enoch's photo), skids 3.5 mm clear of the socket with the slope on the leading edge (they were silently missing: sk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
2026-11-09 JOURNAL: nose parts printed, TFMini notch fix, arm calibration
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2026-11-11 JOURNAL: arms lifted off the dock while Enoch travels; bumper switch travel too short
2026-11-11 scripts: dock_watch.py - unattended arms-down-at-low-battery check for cron (not installed: Arms down missed the rollers on 11-11)
